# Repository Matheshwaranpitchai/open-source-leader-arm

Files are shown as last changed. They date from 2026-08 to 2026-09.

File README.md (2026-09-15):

# Open-source Leader Arm

Open-source, low-cost, 3D-printed leader arm for teleoperating an SO-ARM 

https://github.com/user-attachments/assets/977a0b56-c7d2-4a90-b86a-445dd3963871

A leader arm is moved by an operator to teleoperate a follower robot arm. A leader arm's joints are never driven, they simply report their joint angles, which the follower mirrors. So instead of using expensive servos, a cheap magnetic encoder like the AS5600 can be used. It results in an arm which is lighter to move by hand and is much cheaper than the one built with servos. 

Currently, the leader arm is tested against a simulated SO-ARM in MuJoCo with live physics, so you can pick up and move objects in the scene without a physical follower arm. It also plugs into LeRobot as a teleoperator, so you can record training datasets entirely in simulation.

## Featured Build

Oliver Choy independently built the Leader Arm and documented the process, including the ROS 2 implementation. He'll also be showcasing it at ROSCon 2026. [Read about his build →](https://www.linkedin.com/pulse/building-sub-50-3d-printed-robotic-arm-ros-2-little-oliver-choy-22amc/)

## Bill of materials

|Component| Quantity | Price|
|-|-|-|
|AS5600 encoder + Diametric magnet (5mm dia,2mm thick) | 6 | 6 x 186 INR = 1,116 INR (~11.7 USD)|
|608 Bearing (8x22x7mm) | 6 | 6 x 30 INR = 180 INR (~1.9 USD)|
| CJMCU TCA9548A I2C 8 Channel Multiplexer| 1 | 59 INR (~0.6 USD)|
|ESP32 | 1 | 550 INR (~5.8 USD)|
|28 AWG Silicon Wires | ~5m per color (4 colors) | 477 INR (~ 5 USD)|
|M3x10mm screws | 60 | 195 INR (~2 USD)|
|7x9cm Perfboard | 1 | 42 INR (~0.45 USD)|
| Rubber band | 1 | Negligible|
| |Total | 2,619 INR (~27.45 USD)|

Excluding the price of the 3D printed parts.

For context: the STS3215 servo used in the standard LeRobot leader arm costs around 24 USD each, and the leader arm needs six, roughly 144 USD in servos alone. Our entire component list comes in under 28 USD.

Note: The encoder and diametric magnet almost always come as a combo. Try to buy them together, the diametric magnet on its own can be difficult to source. 

## How it works?
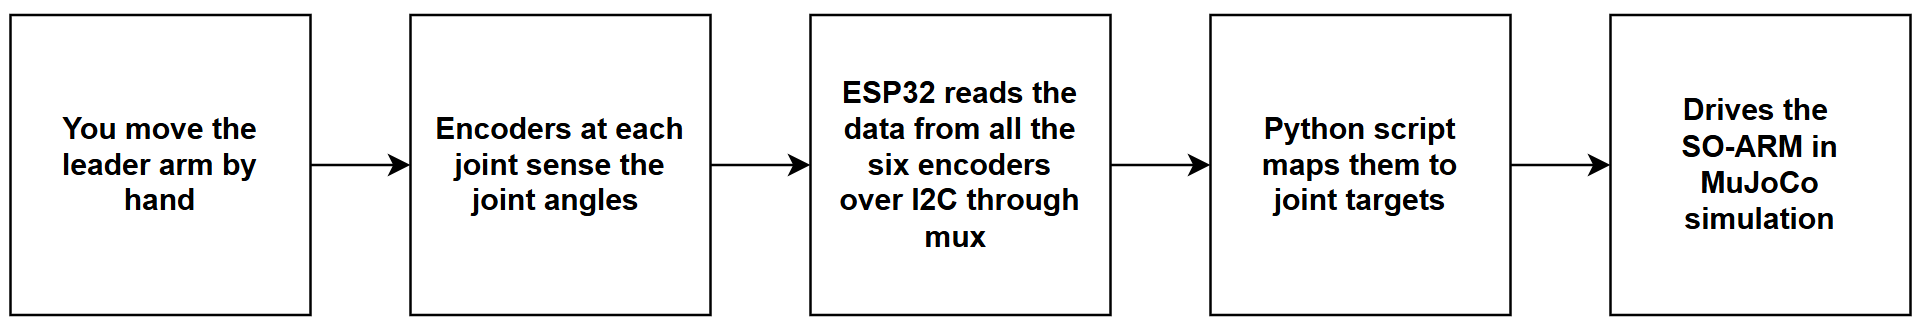
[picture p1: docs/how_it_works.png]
How it works explainer


**Why a mux?** - The AS5600 encoder has a fixed I2C address (0x36) and can't be changed. So we can't put more than one on a bus as they will all share the same address. The TCA9548A mux gives each encoder its own separate channel and connects one channel to the ESP32 at a time, so all six encoders can be read without any collision. 

## Wiring
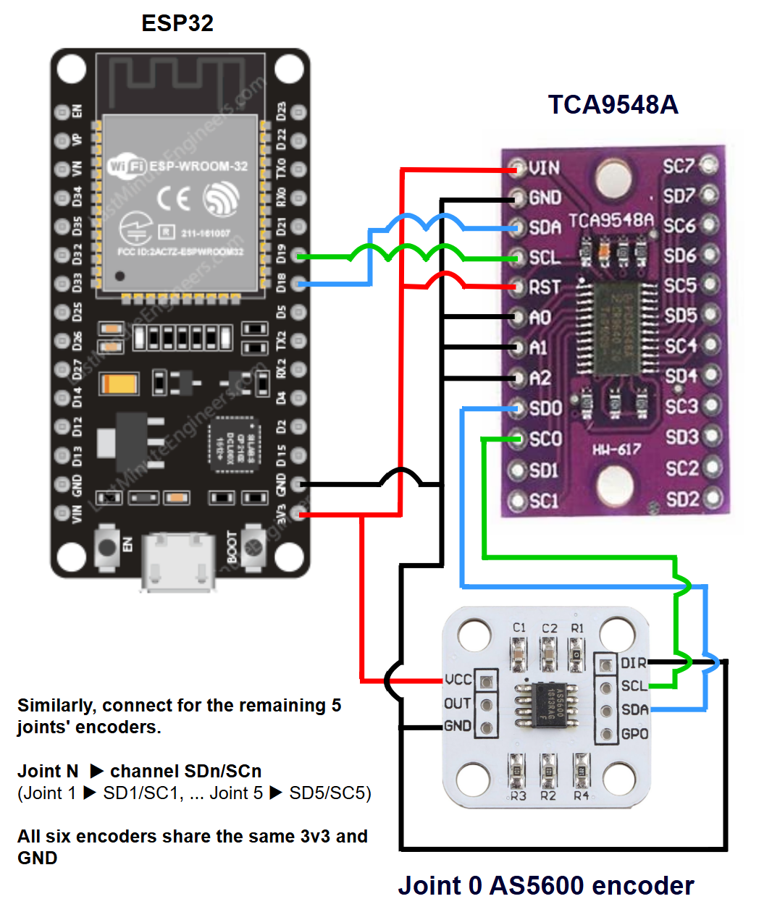
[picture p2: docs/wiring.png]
wiring diagram


| TCA9548A | ESP32 | 
| --- | --- |
| VIN | 3V3 |
| GND | GND |
| SDA | D18 |
| SCL | D19 |
| RST | 3V3 |
| A0, A1, A2 | GND |

| AS5600 | ESP32 |
| --- | --- |
| VCC | 3V3 |
| GND, DIR | GND |

| AS5600 | TCA9548A |
|---|---|
| SDA | SDn |
| SCL | SCn |

n = the channel for that joint \
joint 0 → SD0/SC0, ... joint 5 → SD5/SC5

## Print Settings

Printed in PLA, 0.2mm layer height and 15% infill.

There are 19 unique parts and a total of 49 parts. All the parts are designed to not need support while printing. All the parts are already oriented for printing; if any part loads at an odd angle, lay its flat face on the bed. 

The part 'bearing_housing' needs a bearing inserted mid-print. Add a pause at 10mm height (layer 50 at 0.2mm layer height setting). In Bambu studio, right-click the corresponding layer on the vertical slider and choose "Add Pause". When the printer pauses, insert the 608 bearing into the pocket, make sure it is seated flat, and then resume.

### Parts list and count

```
1 x base
1 x base_connector
6 x bearing_housing
6 x encoder_housing
5 x encoder_housing_cap
6 x rotor 
3 x link_perpendicular_base
3 x link_perpendicular_body
1 x link_shoulder_to_elbow
1 x link_elbow_to_wrist
1 x link_tooltip 
3 x washer_perpendicular_link 
3 x washer_round
1 x handle_base
1 x handle_body
1 x rest_pose_holder_base
1 x rest_pose_holder_body
3 x wire_holder
2 x rubberband_housing
```

## Firmware

Flash firmware.ino to the ESP32 using the Arduino IDE: 

1. Install the ESP32 board support (Tools → Board → Boards Manager → search "esp32")
2. Open 'firmware/firmware.ino' and select your ESP32 board and port, and upload.
3. After uploading, open the serial monitor at **115200 baud rate** to check the output.

The firmware uses only the built-in 'Wire' library, so there's nothing else to install.

On boot it prints a channel scan, one line per channel, naming whatever is wrong: "no device at 0x36" for a wiring or power fault, or "magnet too weak / too far", "too strong / too close" or "not detected" for a magnet fault.

If everything works then it prints "magnet ok"

Example : # ch0: AS5600 found, magnet ok, raw 1234

After the scan, it streams the six encoder readings as a comma-separated line, at 100 Hz. A channel that cannot be read sends "-1" in place of its angle.

## Running the software

Two ways to drive the follower arm: using LeRobot plugins (recommended), which work with a physical or a simulated follower, or the standalone scripts, which drive the simulated follower only. The follower arm in both methods starts in the SO-ARM rest pose, so hold the leader in its reference pose and press ENTER when prompted. That aligns both arms.

### Simulator setup

Skip this if you are using a physical follower. The simulator needs the SO-ARM model from MuJoCo Menagerie; the full repo is 2.35 GB, so pull only the SO-ARM100 folder (6.5 MB).
From the repo root:
```bash
git clone --depth 1 --filter=blob:none --sparse https://github.com/google-deepmind/mujoco_menagerie.git
cd mujoco_menagerie
git sparse-checkout set trs_so_arm100
cd ..
```
### Method 1 - using LeRobot plugins

Two plugins in this repo make the arm work inside [LeRobot](https://github.com/huggingface/lerobot):

- `lerobot_teleoperator_encoder_leader` - registers this leader arm as a LeRobot `Teleoperator`, so it replaces the servo leader in LeRobot's standard commands.
- `lerobot_robot_mujoco_so_arm` - registers a MuJoCo-simulated SO-ARM100 as a LeRobot `Robot`, so you can run the whole pipeline without a physical follower.

From the repo root (Python 3.10 or newer):
```bash
pip install lerobot
pip install -e lerobot_teleoperator_encoder_leader
pip install -e lerobot_robot_mujoco_so_arm
```

#### Teleoperate the arm

```bash
lerobot-teleoperate `
  --robot.type=so101_follower --robot.port=COM6 --robot.id=my_follower `
  --teleop.type=encoder_leader --teleop.port=COM3 --teleop.id=my_leader
```

Replace `COM3` with your ESP32's port. It's the same one the Arduino IDE showed when you flashed the firmware; on Linux and macOS it looks like `/dev/ttyUSB0`. Replace `COM6` with your follower's port.

When prompted, make sure the follower is in its rest pose, then hold the leader in its reference pose and press ENTER. That zeroes the encoders against the follower's rest pose.

Swap `--robot.type=mujoco_so_arm --robot.id=sim --robot.scene=mujoco_menagerie/trs_so_arm100/scene.xml` and drop `--robot.port` to drive the follower in simulation.

#### Record a dataset with a physical follower

```bash
lerobot-record `
  --robot.type=so101_follower --robot.port=COM6 --robot.id=my_follower `
  --robot.cameras="{top: {type: opencv, index_or_path: 0, width: 640, height: 480, fps: 30}, wrist: {type: opencv, index_or_path: 1, width: 640, height: 480, fps: 30}}" `
  --teleop.type=encoder_leader --teleop.port=COM3 --teleop.id=my_leader `
  --dataset.repo_id=<hf_user>/so_arm_sort --dataset.num_episodes=50 `
  --dataset.single_task="Put the red block in the left bin"
```
Replace `<hf_user>` with your huggingface username.
For more, see [Record a dataset](https://huggingface.co/docs/lerobot/main/en/lerobot-dataset-v3#record-a-dataset) in the LeRobot docs.

#### Record a dataset in simulation

```bash
lerobot-record `
  --robot.type=mujoco_so_arm --robot.id=sim `
  --robot.scene=mujoco_menagerie/trs_so_arm100/scene.xml --robot.viewer=true `
  --teleop.type=encoder_leader --teleop.port=COM3 --teleop.id=my_leader `
  --dataset.repo_id=<hf_user>/so_arm_sort --dataset.num_episodes=50 `
  --dataset.single_task="Put the red block in the left bin"
```
Replace `<hf_user>` with your huggingface username.
The scene comes with a block-sorting task: three coloured blocks and three matching bins.

Between episodes the blocks get rearranged into new positions. The plugin watches the same keys `lerobot-record` already uses (Right/Left, or `n`/`r`), so there is nothing extra to press and nothing to do during the reset window.

If you end episodes by timeout rather than by keypress, match both of `lerobot-record`'s timers or the episode tracking drifts:

```bash
  --dataset.episode_time_s=30 --robot.episode_time_s=30 `
  --dataset.reset_time_s=10  --robot.reset_time_s=10
```

Set the recording rate with `--dataset.fps` (default is 30). On integrated graphics 30 is about the limit; drop to 25 if the loop lags behind it.

Shadows and reflections are left out of the recorded images to keep the render cheap.

### Method 2 - using standalone scripts

No LeRobot needed; the encoder stream drives MuJoCo directly.

```bash
pip install "mujoco>=3.2" pyserial
```
Run either one.
```bash
python teleop.py --port COM3              # plain teleop, empty scene
python teleop_sort_task.py --port COM3    # teleop + block sorting
```

On Linux, the port looks like `/dev/ttyUSB0`.

In `teleop_sort_task.py`, press `R` in the viewer to reset the blocks.

## Assembly guide

This leader arm has six joints, `joint_0` to `joint_5`.
### Before you start : 
- See the print settings section for the full parts list and count
- Use the images in the guide for parts orientation and alignment. The assembly files under cad_files are also helpful for this.
- Notation : A + B means "attach part B to part A or assembly A". assembly_step_N refers to the result of step N. 
- Only joint_0 and joint_5 get their encoder attached immediately. The remaining four joints get their encoders at the very end, so that there is less wire clutter during the assembly.
 
### Steps : 
1. Start by wiring all the six encoders as shown in `wiring.png`.
2. insert the diametric magnet into the circular pocket provided in the `rotor` (for all 6 rotors)
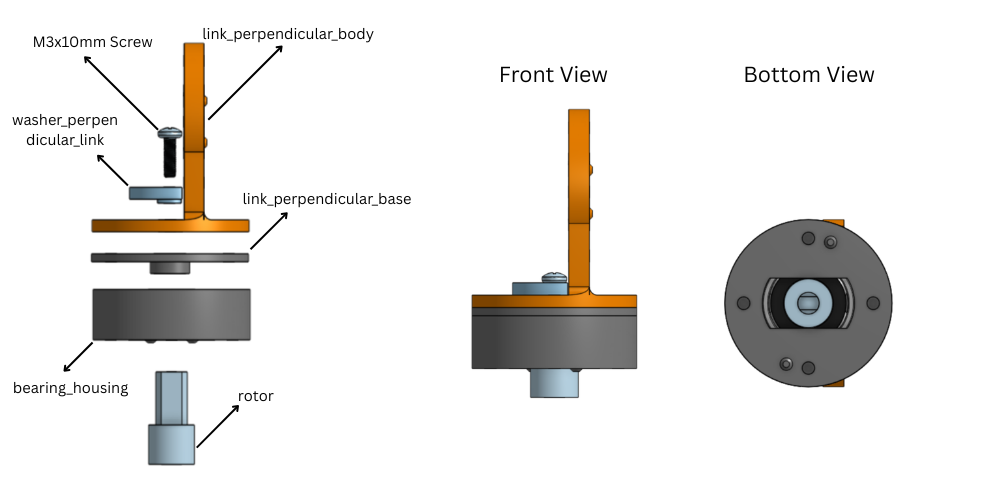
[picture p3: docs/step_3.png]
step_3
3. `rotor + bearing_housing + link_perpendicular_base + link_perpendicular_body + washer_perpendicular_link` (`joint_0`)
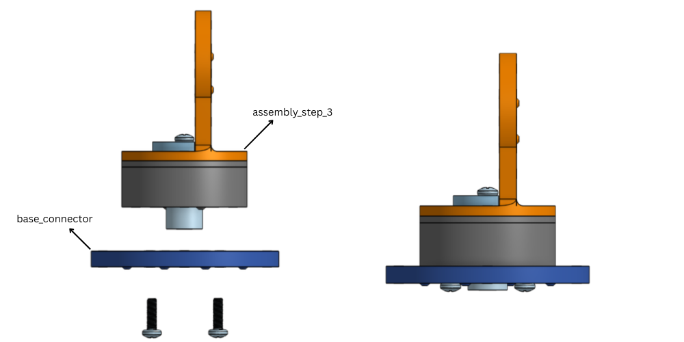
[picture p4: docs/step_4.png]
step_4
4. `assembly_step_3 + base_connector` 
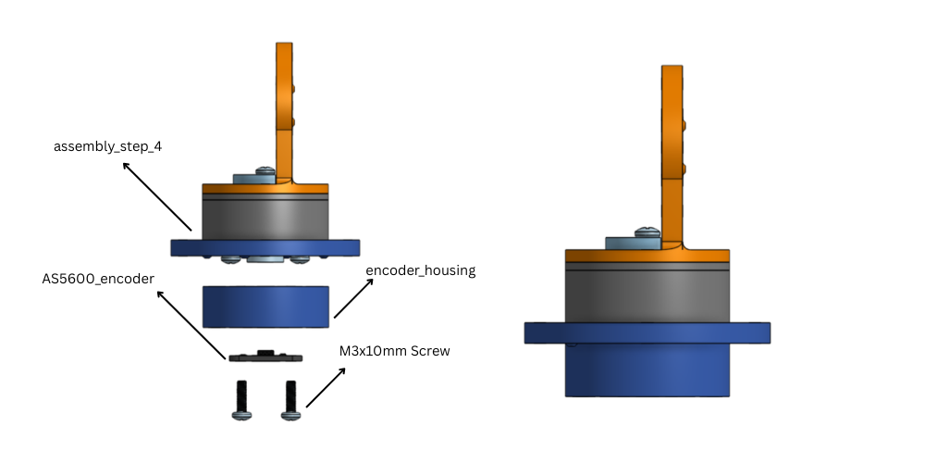
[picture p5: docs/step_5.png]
step_5
5. `assembly_step_4 + encoder_housing + AS5600_encoder` 
6. Tie a knot in the wire, then attach the `encoder_housing_cap`, so that a wire pull doesn't act on the encoder. 
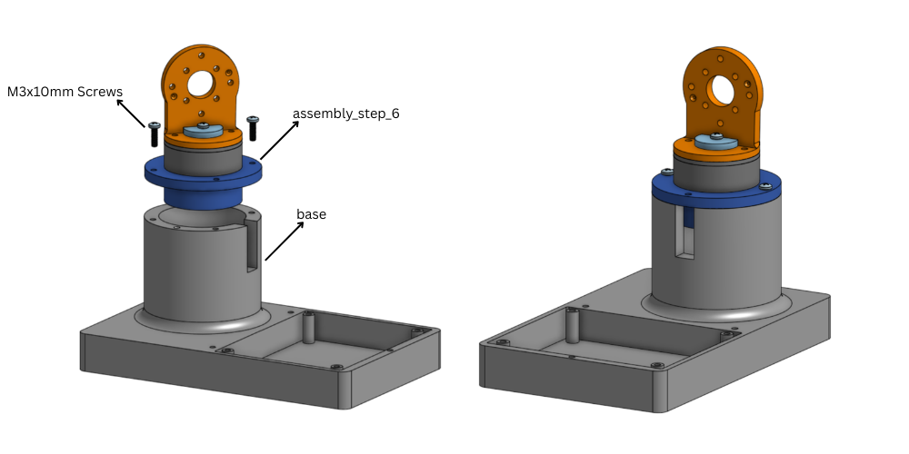
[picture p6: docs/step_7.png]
step_7
7. `assembly_step_6 + base` 
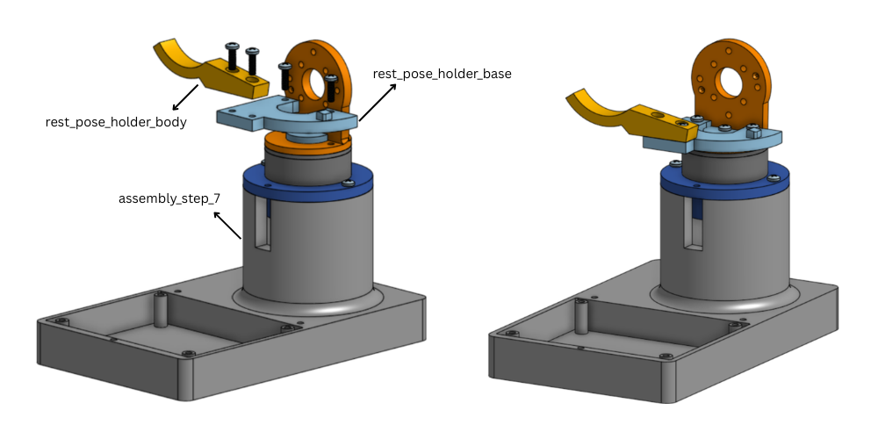
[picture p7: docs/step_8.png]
step_8
8. `assembly_step_7 + rest_pose_holder_base + rest_pose_holder_body` 
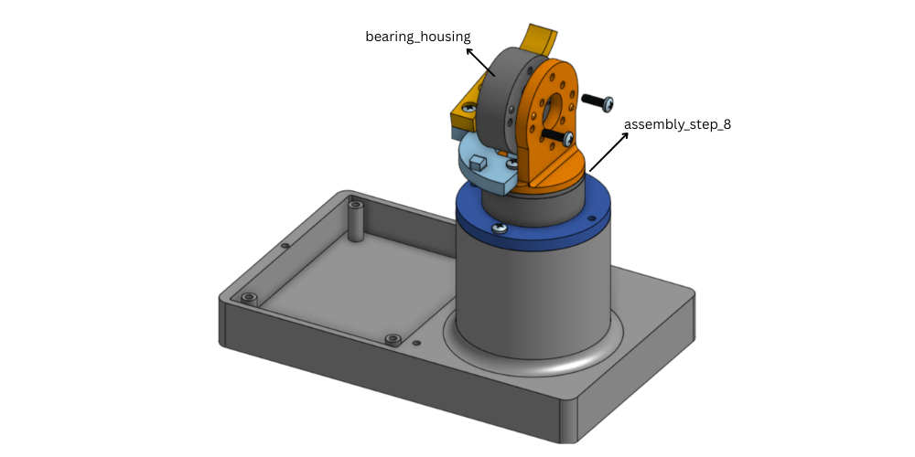
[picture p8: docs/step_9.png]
step_9
9. `assembly_step_8 + bearing_housing` 
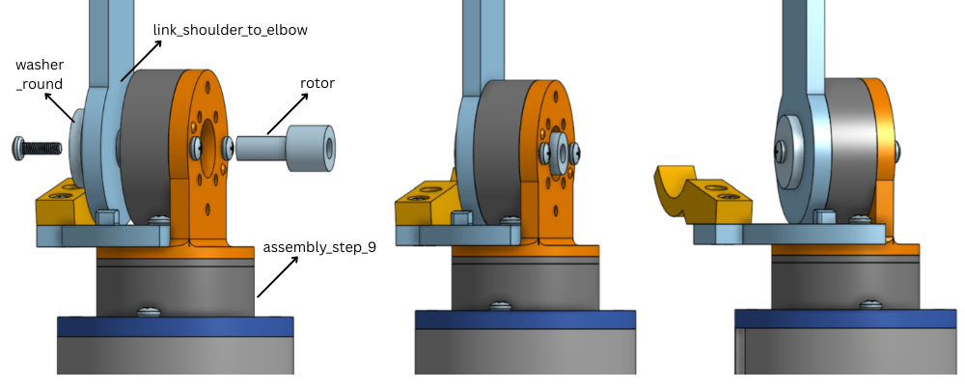
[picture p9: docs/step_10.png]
step_10
10. `assembly_step_9 + rotor + link_shoulder_to_elbow + washer_round` (`joint_1`) 
11. `link_shoulder_to_elbow + bearing_housing` (similar to step 9)
12. `assembly_step_11 + rotor + link_elbow_to_wrist + washer_round` (similar to step 10) (`joint_2`)
13. `link_elbow_to_wrist + bearing_housing` (similar to step 11)
14. `assembly_step_13 + rotor + link_perpendicular_base + link_perpendicular_body + washer_perpendicular_link` (similar to step 3) (`joint_3`)
15. `assembly_step_14 + bearing_housing` (similar to step 9)
16. `assembly_step_15 + rotor + link_perpendicular_base + link_perpendicular_body + washer_perpendicular_link` (similar to step 14) (`joint_4`)
17. `assembly_step_16 + bearing_housing` (similar to steps 9 and 15)
18. `assembly_step_17 + rotor + link_tooltip + washer_round` (`joint_5`)
19. `assembly_step_18 + encoder_housing + AS5600_encoder`
20. Tie a knot in the wire as in step 6
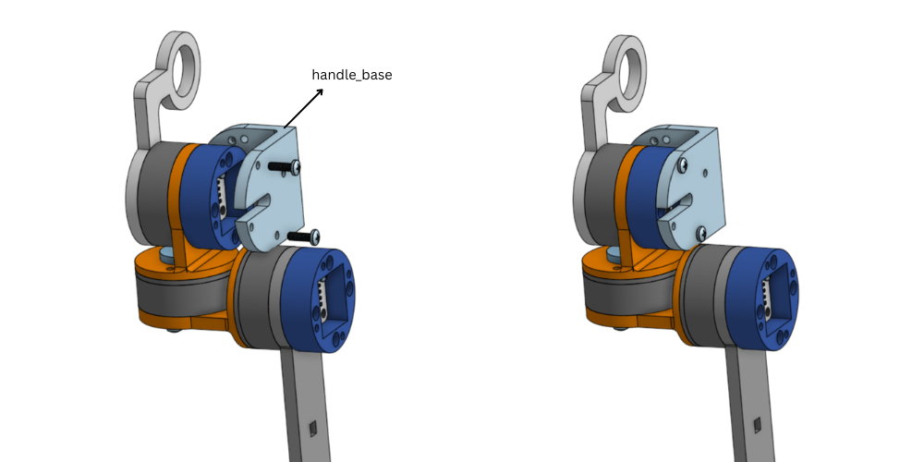
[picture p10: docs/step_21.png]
step_21
21. `assembly_step_20 + handle_base` (the `handle_base` also acts here as the `encoder_housing_cap`) 
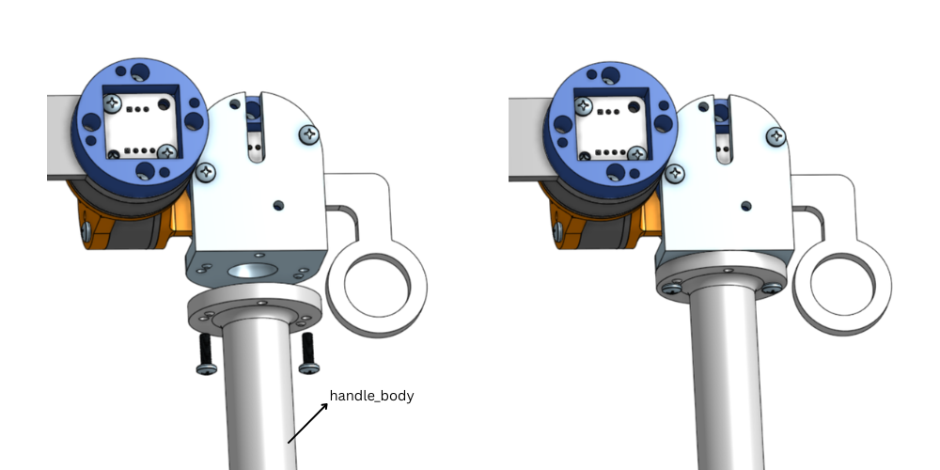
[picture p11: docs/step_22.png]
step_22
22. `assembly_step_21 + handle_body` 
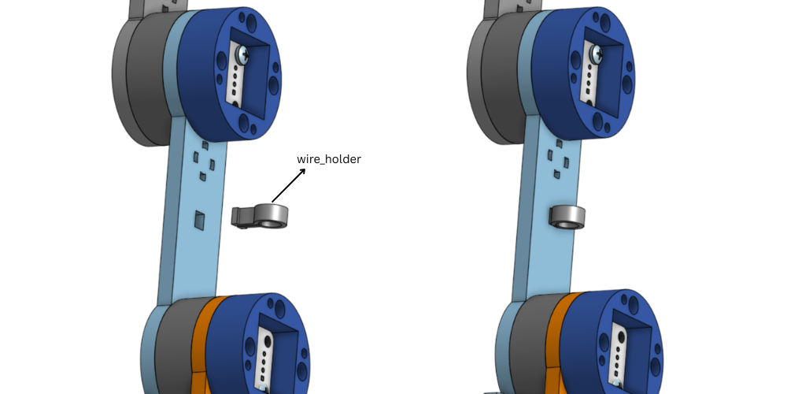
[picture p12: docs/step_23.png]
step_23
23. attach the three `wire_holder`s on `link_shoulder_to_elbow` and `link_elbow_to_wrist`. 
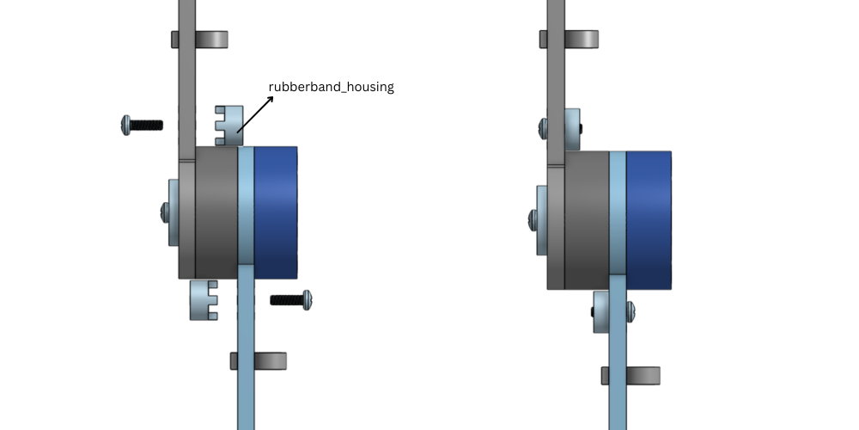
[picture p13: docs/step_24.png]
step_24
24. Route a single rubberband through both `rubberband_housings`, then fix one housing to `link_shoulder_to_elbow` and one to `link_elbow_to_wrist`. 
25. attach the `encoder_housing + AS5600_encoder`, tie a knot, and attach the `encoder_housing_cap` for the four remaining joints, in the same way as step 5 or step 19. 

## Acknowledgements

This project builds on the work of several open-source projects:

- [SO-ARM100](https://github.com/TheRobotStudio/SO-ARM100) - the follower arm design this leader is built to teleoperate.
- [LeRobot](https://github.com/huggingface/lerobot) - the leader/follower teleoperation approach this project is based on.
- [MuJoCo Menagerie](https://github.com/google-deepmind/mujoco_menagerie) - the SO-ARM model used by the simulated follower.

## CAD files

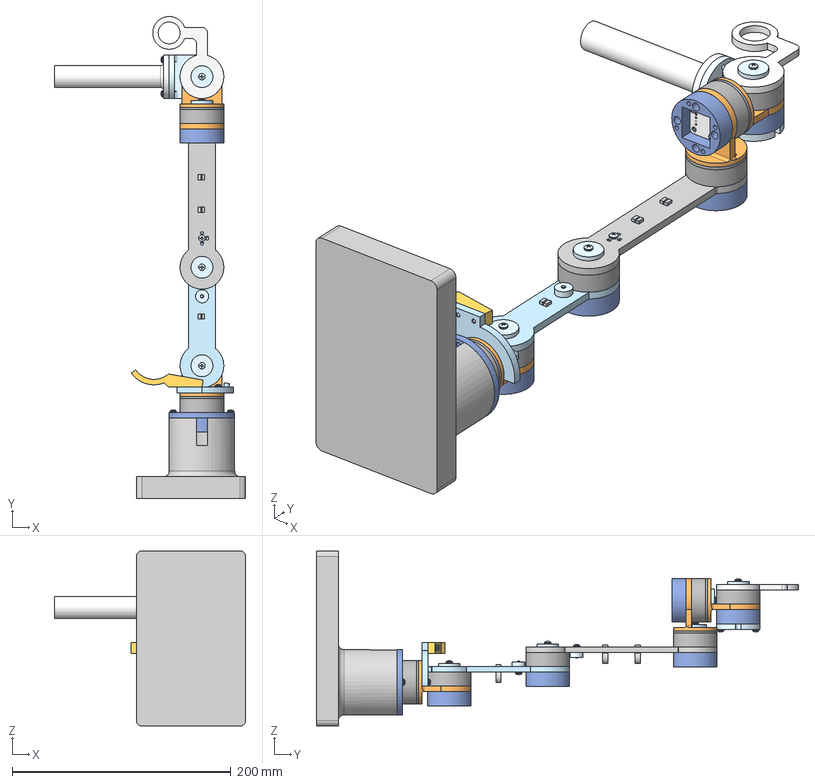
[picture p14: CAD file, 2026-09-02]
cad_files/assembly.step
175.0 x 440.7 x 160.0 mm
washer_round x 3
M3x10 PH Screw x 43
handle-body
bearing_housing x 6
washer_perpendicular_link x 3
rotor x 6
link_shoulder_to_elbow
608 bearing x 6
handle_base
rest_pose_holder_base
link_perpendicular_base x 3
wire_holder x 3
encoder_housing x 6
rest_pose_holder_body
link_perpendicular_body x 3
rubberband_housing x 2
base_connector
base
link_elbow_to_wrist
link_tooltip

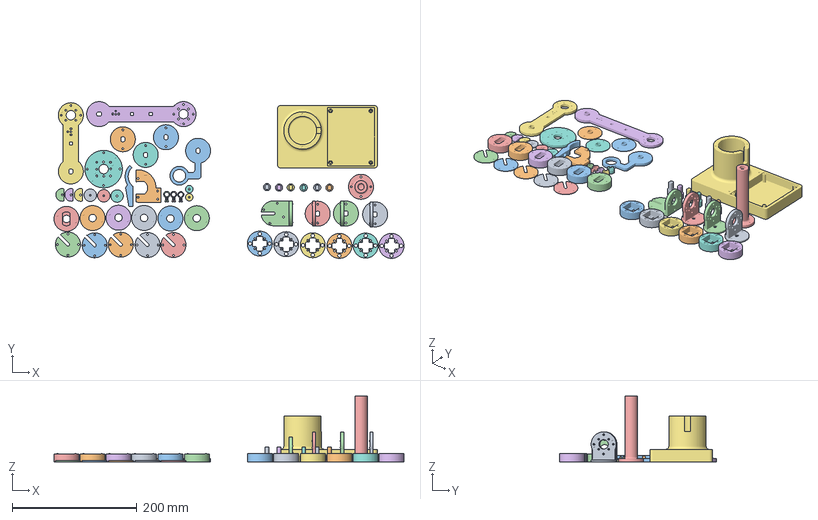
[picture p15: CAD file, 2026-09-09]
cad_files/leader_arm_all_parts_bambulab_a1.3mf
560.1 x 250.9 x 105.0 mm
bearing_housing.stl x 6
base.stl
base_connector.stl
encoder_cap.stl x 5
encoder_housing.stl x 6
handle_base.stl
handle_body.stl
link_elbow_to_wrist.stl
link_shoulder_to_elbow.stl
link_perpendicular_base.stl x 3
link_perpendicular_body.stl x 3
rotor.stl x 6
link_tooltip.stl
washer_perpendicular_link.stl x 3
washer_round.stl x 3
rest_pose_holder_base.stl
rest_pose_holder_body.stl
wire_holder.stl x 3
rubberband_housing.stl x 2

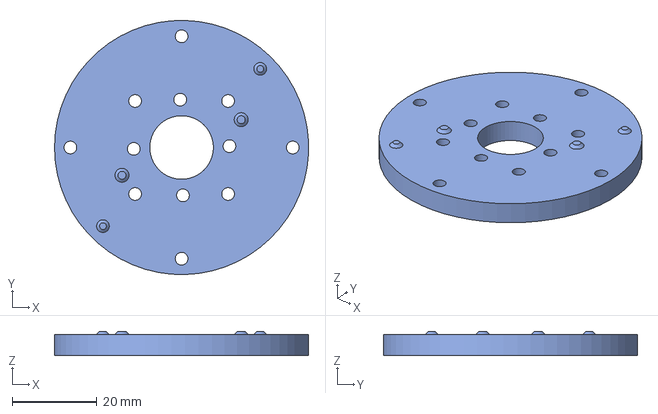
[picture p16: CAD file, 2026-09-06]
cad_files/step/base_connector.step
60.0 x 60.0 x 5.70 mm

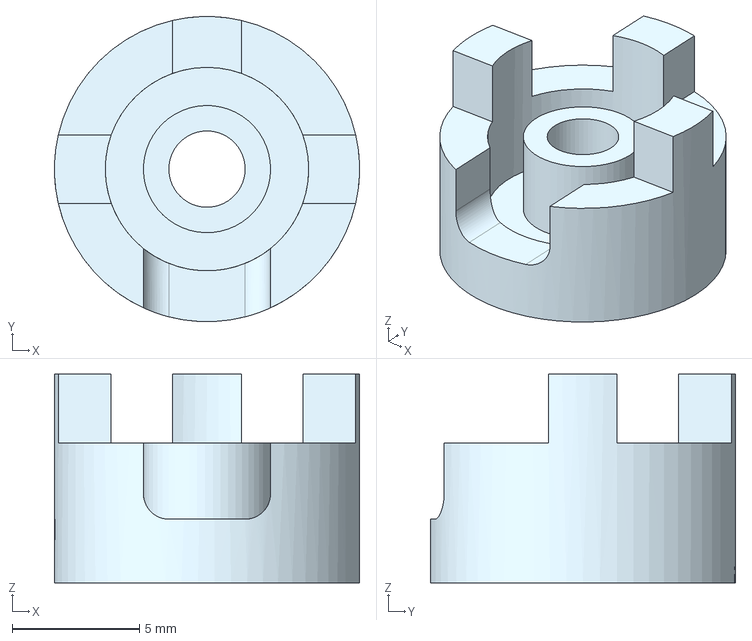
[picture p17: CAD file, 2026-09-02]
cad_files/step/rubberband_housing.step
12.0 x 12.0 x 8.20 mm

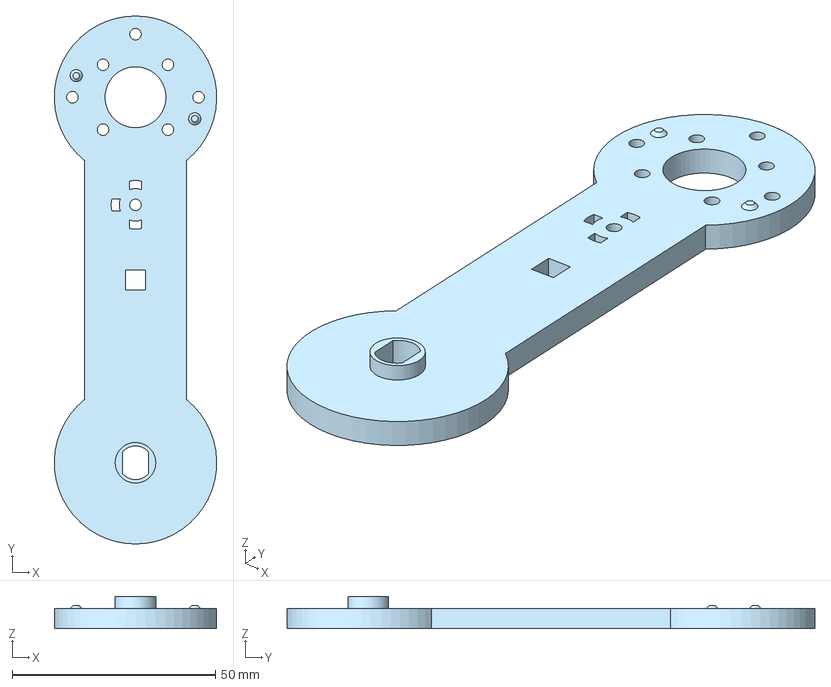
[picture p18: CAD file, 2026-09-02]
cad_files/step/link_shoulder_to_elbow.step
40.0 x 130.0 x 8.00 mm

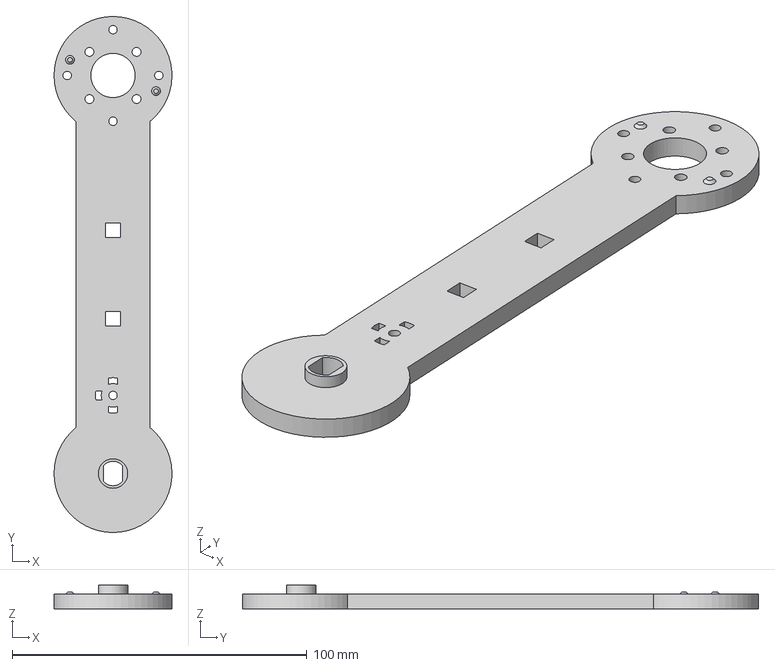
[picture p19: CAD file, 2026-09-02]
cad_files/step/link_elbow_to_wrist.step
40.0 x 175.0 x 8.00 mm

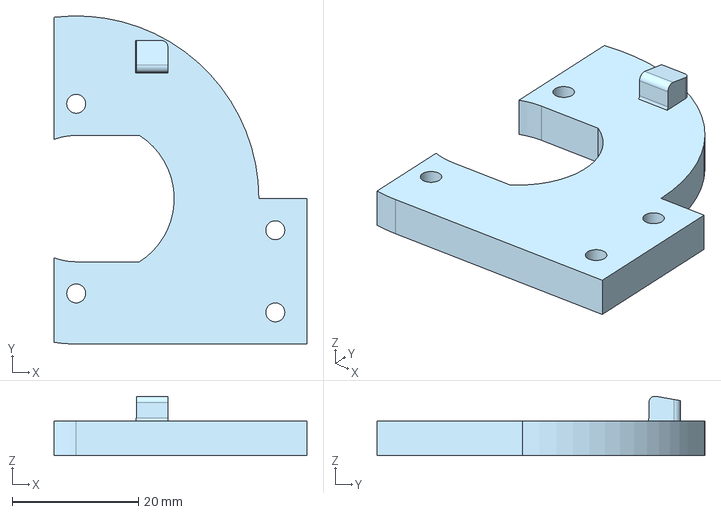
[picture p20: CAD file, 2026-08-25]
cad_files/step/rest_pose_holder_base.step
40.0 x 51.9 x 9.41 mm

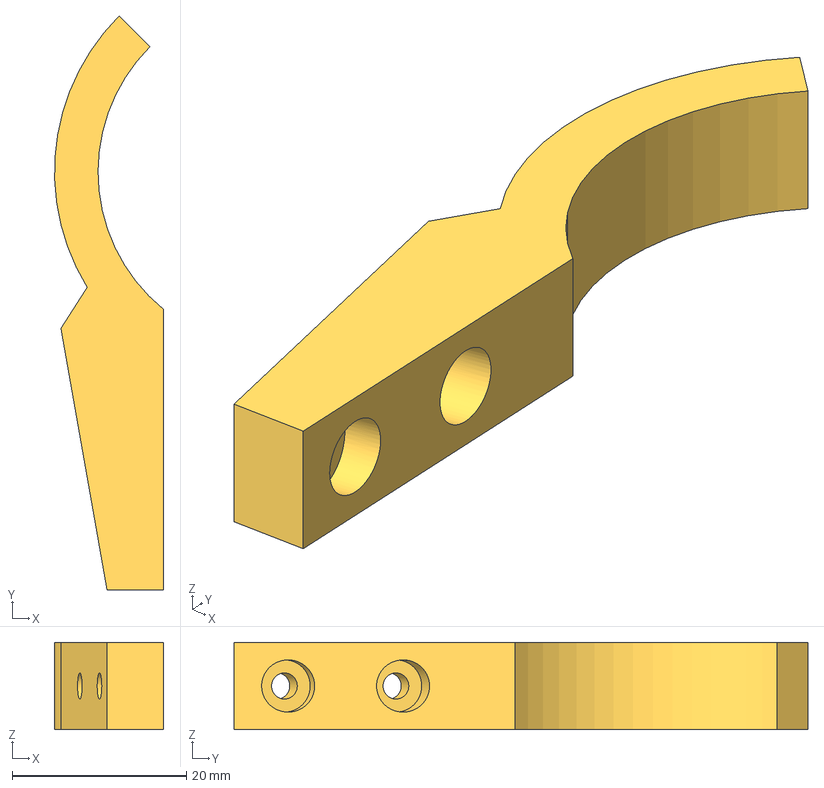
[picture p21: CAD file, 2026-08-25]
cad_files/step/rest_pose_holder_body.step
12.5 x 65.9 x 10.0 mm

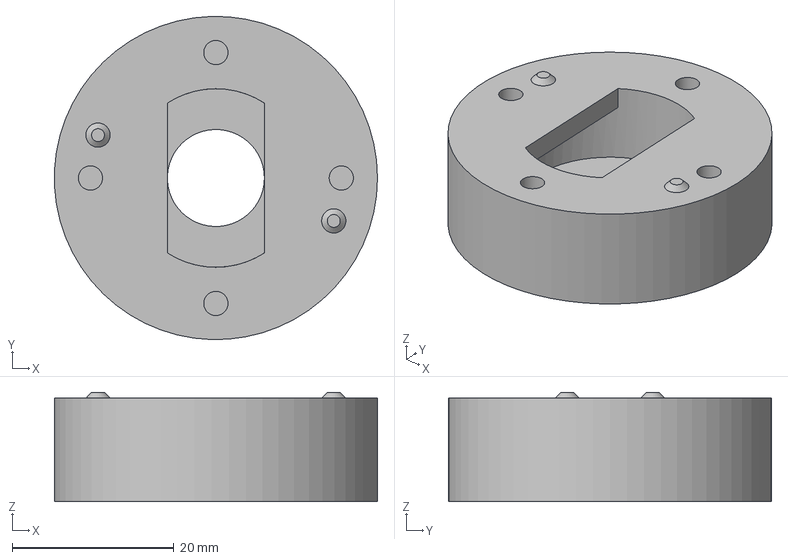
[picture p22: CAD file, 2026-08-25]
cad_files/step/bearing_housing.step
40.0 x 40.0 x 13.5 mm

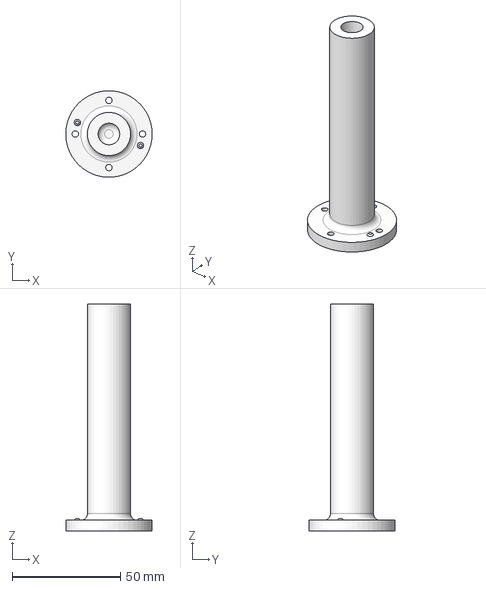
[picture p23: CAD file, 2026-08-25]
cad_files/step/handle_body.step
40.0 x 40.0 x 105.0 mm

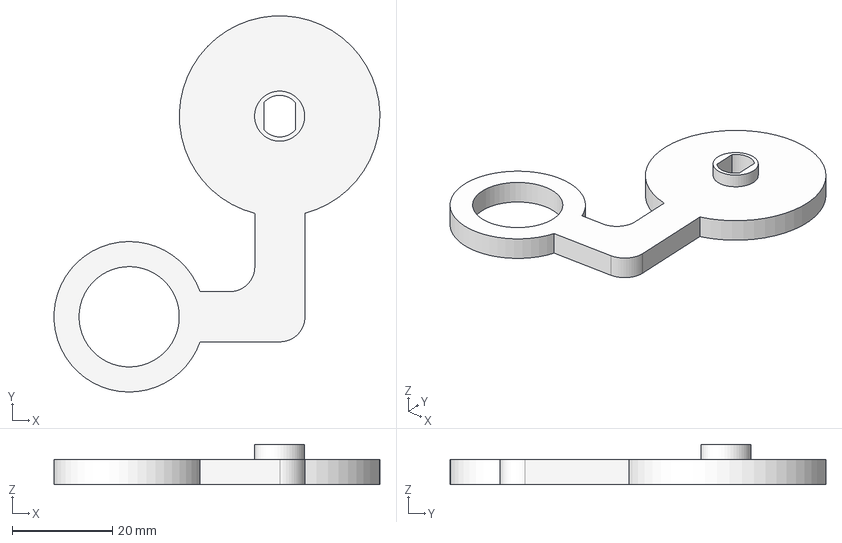
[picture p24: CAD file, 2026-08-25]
cad_files/step/link_tooltip.step
65.0 x 75.0 x 8.00 mm

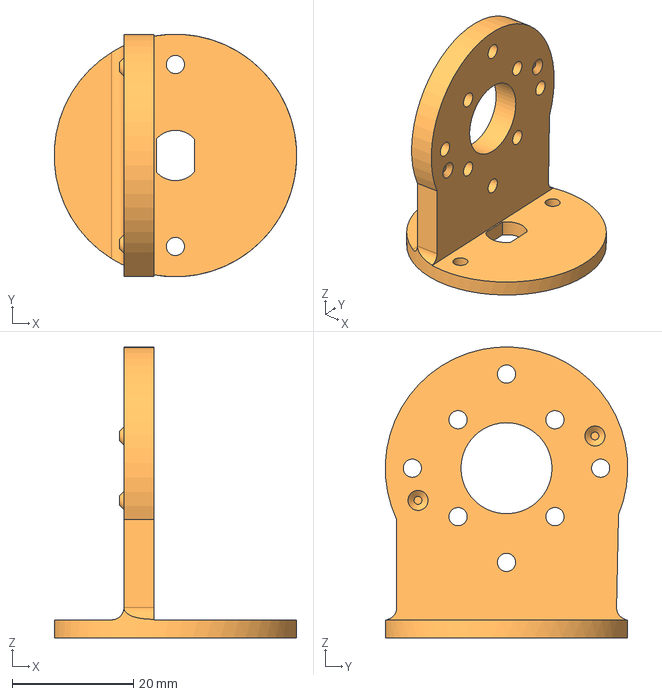
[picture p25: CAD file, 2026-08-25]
cad_files/step/link_perpendicular_body.step
40.0 x 40.0 x 48.0 mm

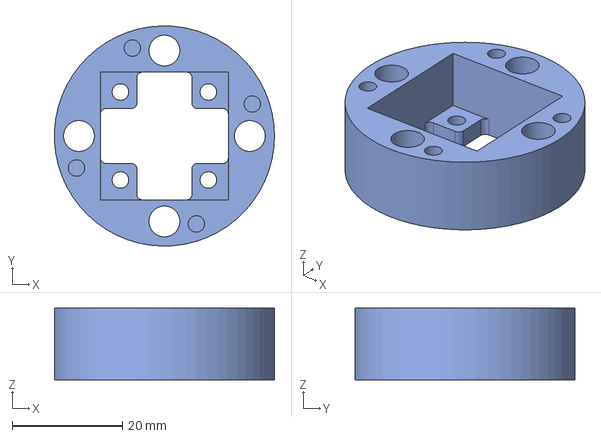
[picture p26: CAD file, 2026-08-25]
cad_files/step/encoder_housing.step
40.0 x 40.0 x 13.0 mm

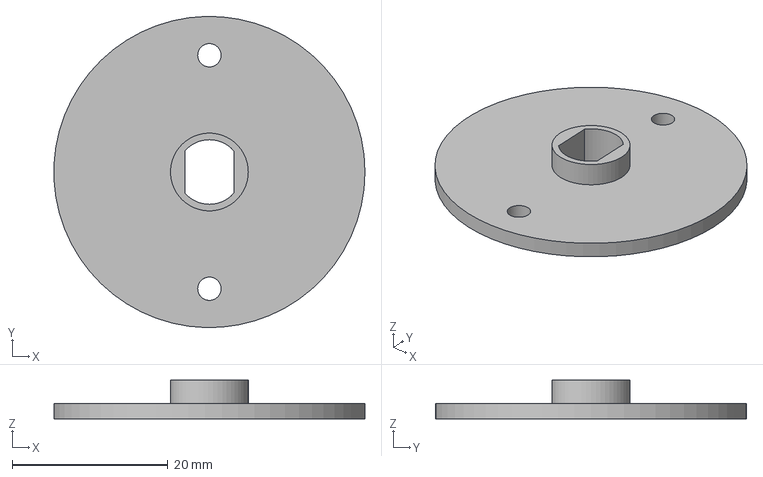
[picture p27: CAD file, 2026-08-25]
cad_files/step/link_perpendicular_base.step
40.0 x 40.0 x 5.00 mm

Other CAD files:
cad_files/step/link_elbow_to_shoulder.step
cad_files/step/wire_holder.step
cad_files/step/handle_base.step
cad_files/step/encoder_cap.step
cad_files/step/base.step
cad_files/step/rotor.step
cad_files/step/washer_perpendicular_link.step
cad_files/step/washer_round.step
cad_files/stl/base.stl
cad_files/stl/base_connector.stl
cad_files/stl/bearing_housing.stl
cad_files/stl/encoder_cap.stl
cad_files/stl/encoder_housing.stl
cad_files/stl/handle_base.stl
cad_files/stl/handle_body.stl
cad_files/stl/link_elbow_to_shoulder.stl
cad_files/stl/link_elbow_to_wrist.stl
cad_files/stl/link_perpendicular_base.stl
cad_files/stl/link_perpendicular_body.stl
cad_files/stl/link_shoulder_to_elbow.stl
cad_files/stl/link_tooltip.stl
cad_files/stl/rest_pose_holder_base.stl
cad_files/stl/rest_pose_holder_body.stl
cad_files/stl/rotor.stl
cad_files/stl/rubberband_housing.stl
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

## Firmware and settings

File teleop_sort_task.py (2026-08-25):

import argparse
import math
import time

import mujoco
import mujoco.viewer
import serial

SCENE = "mujoco_menagerie/trs_so_arm100/scene.xml"
COUNTS_PER_REV = 4096
RAD_PER_COUNT = 2 * math.pi / COUNTS_PER_REV

CHANNEL_TO_JOINT = {0: 0, 1: 1, 2: 2, 3: 3, 4: 4, 5: 5}
HOME_ANGLE = {0: -0.4517, 1: -3.32, 2: 3.1078, 3: 1.2338, 4: 0.1391, 5: -0.174}
DIRECTION = {0: -1, 1: -1, 2: -1, 3: -1, 4: 1, 5: 1}
SCALE = {0: 1.0, 1: 1.0, 2: 1.0, 3: 1.0, 4: 1.0, 5: 1.0}

BLOCK_SIZE = 0.015
BLOCK_MASS = 0.03
FRICTION = [1.2, 0.05, 0.001]
GRIP_GAIN = None

_Z = BLOCK_SIZE + 0.001
FORWARD_OFFSET = -0.10

COLORS = {
    "red":   [0.85, 0.20, 0.20, 1.0],
    "green": [0.20, 0.70, 0.25, 1.0],
    "blue":  [0.20, 0.45, 0.85, 1.0],
}

BLOCK_LAYOUT = [
    (-0.12, -0.20, "green"), (0.00, -0.20, "blue"), (0.12, -0.20, "red"),
]

BINS = [
    (-0.16, -0.36, "red"),
    (0.00, -0.36, "green"),
    (0.16, -0.36, "blue"),
]
BIN_HALF = [0.05, 0.05]
BIN_WALL = 0.004
BIN_WALL_H = 0.0125


def _blocks_spec():
    out = []
    for i, (x, y, color) in enumerate(BLOCK_LAYOUT):
        out.append({
            "name": f"block_{color}_{i}",
            "pos": [x, y + FORWARD_OFFSET, _Z],
            "color": color,
            "rgba": COLORS[color],
        })
    return out


BLOCKS = _blocks_spec()
BINS_ADJ = [(x, y + FORWARD_OFFSET, color) for (x, y, color) in BINS]


class Unwrapper:
    def __init__(self):
        self.last = None
        self.total = 0

    def update(self, raw):
        if raw < 0:
            return self.total
        if self.last is None:
            self.last = raw
        d = raw - self.last
        if d > COUNTS_PER_REV // 2:
            d -= COUNTS_PER_REV
        elif d < -COUNTS_PER_REV // 2:
            d += COUNTS_PER_REV
        self.last = raw
        self.total += d
        return self.total


def latest_line(ser, buf):
    buf += ser.read(ser.in_waiting or 1)
    if b"\n" not in buf:
        return None, buf
    *complete, buf = buf.split(b"\n")
    for line in reversed(complete):
        line = line.strip()
        if line and not line.startswith(b"#"):
            return line, buf
    return None, buf


def parse_counts(line):
    try:
        return [int(x) for x in line.split(b",")]
    except ValueError:
        return None


def read_good_counts(ser):
    buf = b""
    need = max(CHANNEL_TO_JOINT) + 1
    last_report = 0
    last_line = None
    while True:
        line, buf = latest_line(ser, buf)
        if line is not None:
            last_line = line
            counts = parse_counts(line)
            if counts and len(counts) >= need and all(
                counts[c] >= 0 for c in CHANNEL_TO_JOINT
            ):
                return counts
        now = time.time()
        if now - last_report > 1.0:
            last_report = now
            if last_line is None:
                print("  waiting... no serial data yet (right port? streaming?)")
            else:
                counts = parse_counts(last_line)
                if not counts:
                    print(f"  waiting... unreadable line: {last_line!r}")
                elif len(counts) < need:
                    print(f"  waiting... only {len(counts)} values, need {need}"
                          f" -- re-flash firmware with N_CH={need}")
                else:
                    bad = [c for c in CHANNEL_TO_JOINT if counts[c] < 0]
                    print(f"  waiting... channel(s) {bad} reading -1"
                          f" -- fix that encoder's magnet/wiring")


def _add_bin(spec, cx, cy, color):
    name = f"bin_{color}"
    bhx, bhy = BIN_HALF
    wt, wh = BIN_WALL, BIN_WALL_H
    pad_rgba = COLORS[color]
    wall_rgba = [pad_rgba[0], pad_rgba[1], pad_rgba[2], 0.40]

    body = spec.worldbody.add_body(name=name, pos=[cx, cy, 0.0])

    pad = body.add_geom()
    pad.name = f"{name}_pad"
    pad.type = mujoco.mjtGeom.mjGEOM_BOX
    pad.size = [bhx + 2 * wt, bhy + 2 * wt, 0.001]
    pad.pos = [0.0, 0.0, 0.001]
    pad.rgba = pad_rgba

    walls = [
        (f"{name}_e", [bhx + wt, 0.0, wh], [wt, bhy + 2 * wt, wh]),
        (f"{name}_w", [-(bhx + wt), 0.0, wh], [wt, bhy + 2 * wt, wh]),
        (f"{name}_n", [0.0, bhy + wt, wh], [bhx + 2 * wt, wt, wh]),
        (f"{name}_s", [0.0, -(bhy + wt), wh], [bhx + 2 * wt, wt, wh]),
    ]
    for gname, gpos, gsize in walls:
        w = body.add_geom()
        w.name = gname
        w.type = mujoco.mjtGeom.mjGEOM_BOX
        w.pos = gpos
        w.size = gsize
        w.rgba = wall_rgba


def build_model():
    spec = mujoco.MjSpec.from_file(SCENE)
    for b in BLOCKS:
        body = spec.worldbody.add_body(name=b["name"], pos=b["pos"])
        body.add_freejoint()
        geom = body.add_geom()
        geom.type = mujoco.mjtGeom.mjGEOM_BOX
        geom.size = [BLOCK_SIZE, BLOCK_SIZE, BLOCK_SIZE]
        geom.rgba = b["rgba"]
        geom.friction = FRICTION
        geom.mass = BLOCK_MASS
    for cx, cy, color in BINS_ADJ:
        _add_bin(spec, cx, cy, color)
    return spec.compile()


def block_registry(model):
    reg = []
    for b in BLOCKS:
        bid = mujoco.mj_name2id(model, mujoco.mjtObj.mjOBJ_BODY, b["name"])
        jid = model.body_jntadr[bid]
        reg.append({
            "name": b["name"],
            "color": b["color"],
            "bid": bid,
            "qadr": model.jnt_qposadr[jid],
            "vadr": model.jnt_dofadr[jid],
            "start": list(b["pos"]),
        })
    return reg


def reset_blocks(model, data, blocks_reg):
    for blk in blocks_reg:
        q = blk["qadr"]
        data.qpos[q:q + 3] = blk["start"]
        data.qpos[q + 3:q + 7] = [1.0, 0.0, 0.0, 0.0]
        v = blk["vadr"]
        data.qvel[v:v + 6] = 0.0
    mujoco.mj_forward(model, data)


def main():
    p = argparse.ArgumentParser()
    p.add_argument("--port", required=True)
    p.add_argument("--baud", type=int, default=115200)
    p.add_argument("--list", action="store_true")
    args = p.parse_args()

    model = build_model()
    data = mujoco.MjData(model)
    blocks_reg = block_registry(model)

    joint_to_act = {}
    for a in range(model.nu):
        if model.actuator_trntype[a] == mujoco.mjtTrn.mjTRN_JOINT:
            joint_to_act[int(model.actuator_trnid[a, 0])] = a

    if args.list:
        for j in range(model.njnt):
            name = mujoco.mj_id2name(model, mujoco.mjtObj.mjOBJ_JOINT, j)
            act = joint_to_act.get(j)
            aname = (mujoco.mj_id2name(model, mujoco.mjtObj.mjOBJ_ACTUATOR, act)
                     if act is not None else "-- no actuator")
            print(f"joint {j}: {name}  -> actuator {act} ({aname})")
        return

    if GRIP_GAIN is not None:
        gjoint = CHANNEL_TO_JOINT[5]
        gact = joint_to_act.get(gjoint)
        if gact is not None:
            model.actuator_gainprm[gact, 0] = GRIP_GAIN

    joints = {}
    for jidx in CHANNEL_TO_JOINT.values():
        act = joint_to_act.get(jidx)
        joints[jidx] = {
            "adr": model.jnt_qposadr[jidx],
            "act": act,
            "lo": model.jnt_range[jidx][0],
            "hi": model.jnt_range[jidx][1],
            "limited": bool(model.jnt_limited[jidx]),
        }
        if act is None:
            print(f"WARNING: joint {jidx} has no actuator; it won't be driven.")

    ser = serial.Serial(args.port, args.baud, timeout=0.05)
    unwrap = {ch: Unwrapper() for ch in CHANNEL_TO_JOINT}
    need = max(CHANNEL_TO_JOINT) + 1

    print("Hold the leader arm in its reference pose, then press ENTER...")
    input()
    home = read_good_counts(ser)
    zero_count = {ch: unwrap[ch].update(home[ch]) for ch in CHANNEL_TO_JOINT}

    for jidx in CHANNEL_TO_JOINT.values():
        data.qpos[joints[jidx]["adr"]] = HOME_ANGLE[jidx]
        if joints[jidx]["act"] is not None:
            data.ctrl[joints[jidx]["act"]] = HOME_ANGLE[jidx]
    mujoco.mj_forward(model, data)
    print("Homed. Sort the blocks into the matching-color bins. "
          "Press R in the viewer to reset the blocks.")

    def clamp(v, jinfo):
        return max(jinfo["lo"], min(jinfo["hi"], v)) if jinfo["limited"] else v

    reset_requested = [False]

    def key_callback(keycode):
        if keycode in (ord("R"), ord("r")):
            reset_requested[0] = True

    buf = b""
    wall0 = time.perf_counter()

    with mujoco.viewer.launch_passive(
        model, data, key_callback=key_callback
    ) as viewer:
        while viewer.is_running():
            if reset_requested[0]:
                reset_requested[0] = False
                reset_blocks(model, data, blocks_reg)

            line, buf = latest_line(ser, buf)
            if line is not None:
                counts = parse_counts(line)
                if counts and len(counts) >= need:
                    for ch, jidx in CHANNEL_TO_JOINT.items():
                        u = unwrap[ch].update(counts[ch])
                        delta = (u - zero_count[ch]) * RAD_PER_COUNT
                        delta *= DIRECTION[jidx] * SCALE[jidx]
                        target = clamp(HOME_ANGLE[jidx] + delta, joints[jidx])
                        act = joints[jidx]["act"]
                        if act is not None:
                            data.ctrl[act] = target

            target_time = time.perf_counter() - wall0
            steps = 0
            while data.time < target_time and steps < 50:
                mujoco.mj_step(model, data)
                steps += 1

            viewer.sync()


if __name__ == "__main__":
    main()

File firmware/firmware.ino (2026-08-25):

#include <Wire.h>

#define MUX_ADDR     0x70
#define AS5600_ADDR  0x36
#define N_CH         6
#define SDA_PIN      18
#define SCL_PIN      19
#define SAMPLE_HZ    100

#define REG_STATUS    0x0B
#define REG_RAW_ANGLE 0x0C

bool muxSelect(uint8_t ch) {
  if (ch >= 8) return false;
  Wire.beginTransmission(MUX_ADDR);
  Wire.write(1 << ch);
  return Wire.endTransmission() == 0;
}

void muxDisableAll() {
  Wire.beginTransmission(MUX_ADDR);
  Wire.write(0x00);
  Wire.endTransmission();
}

int16_t readRawAngle() {
  Wire.beginTransmission(AS5600_ADDR);
  Wire.write(REG_RAW_ANGLE);
  if (Wire.endTransmission(false) != 0) return -1;
  if (Wire.requestFrom(AS5600_ADDR, 2) != 2) return -1;
  uint8_t hi = Wire.read(), lo = Wire.read();
  return ((hi << 8) | lo) & 0x0FFF;
}

uint8_t readStatus() {
  Wire.beginTransmission(AS5600_ADDR);
  Wire.write(REG_STATUS);
  if (Wire.endTransmission(false) != 0) return 0;
  if (Wire.requestFrom(AS5600_ADDR, 1) != 1) return 0;
  return Wire.read();
}

void diagnose() {
  Serial.println("# channel scan");
  for (uint8_t ch = 0; ch < N_CH; ch++) {
    if (!muxSelect(ch)) {
      Serial.printf("# ch%u: mux not responding at 0x%02X\n", ch, MUX_ADDR);
      continue;
    }
    Wire.beginTransmission(AS5600_ADDR);
    if (Wire.endTransmission() != 0) {
      Serial.printf("# ch%u: no device at 0x36 -- check SDn/SCn and power\n", ch);
      continue;
    }
    uint8_t st = readStatus();
    const char *magnet = (st & 0x20) ? "ok"
                       : (st & 0x10) ? "too weak / too far"
                       : (st & 0x08) ? "too strong / too close"
                                     : "not detected";
    Serial.printf("# ch%u: AS5600 found, magnet %s, raw %d\n",
                  ch, magnet, readRawAngle());
  }
  muxDisableAll();
  Serial.println("# scan done");
}

void setup() {
  Serial.begin(115200);
  Wire.begin(SDA_PIN, SCL_PIN);
  Wire.setClock(400000);
  delay(300);
  diagnose();
}

void loop() {
  static uint32_t next = 0;
  const uint32_t period = 1000 / SAMPLE_HZ;
  if (millis() < next) return;
  next = millis() + period;

  int16_t angle[N_CH];
  for (uint8_t ch = 0; ch < N_CH; ch++) {
    angle[ch] = muxSelect(ch) ? readRawAngle() : -1;
  }

  for (uint8_t ch = 0; ch < N_CH; ch++) {
    Serial.print(angle[ch]);
    Serial.print(ch == N_CH - 1 ? '\n' : ',');
  }
}

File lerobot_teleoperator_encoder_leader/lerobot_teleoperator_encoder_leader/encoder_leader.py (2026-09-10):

import logging
import math
import time

import serial

from lerobot.teleoperators.teleoperator import Teleoperator
from lerobot.utils.decorators import check_if_already_connected, check_if_not_connected

from .config_encoder_leader import JOINTS, EncoderLeaderConfig

logger = logging.getLogger(__name__)


class _Unwrapper:
    def __init__(self, counts_per_rev: int):
        self.counts_per_rev = counts_per_rev
        self.last: int | None = None
        self.total = 0

    def update(self, raw: int) -> int:
        if raw < 0:
            return self.total
        if self.last is None:
            self.last = raw
        d = raw - self.last
        if d > self.counts_per_rev // 2:
            d -= self.counts_per_rev
        elif d < -self.counts_per_rev // 2:
            d += self.counts_per_rev
        self.last = raw
        self.total += d
        return self.total


class EncoderLeader(Teleoperator):
    config_class = EncoderLeaderConfig
    name = "encoder_leader"

    def __init__(self, config: EncoderLeaderConfig):
        super().__init__(config)
        self.config = config
        self.rad_per_count = 2 * math.pi / config.counts_per_rev
        self._ser: serial.Serial | None = None
        self._buf = b""
        self._unwrap = {ch: _Unwrapper(config.counts_per_rev) for ch in config.channel_to_joint}
        self._zero_count: dict[int, int] = {}


    @property
    def action_features(self) -> dict[str, type]:
        return {f"{j}.pos": float for j in JOINTS}

    @property
    def feedback_features(self) -> dict[str, type]:
        return {}


    @property
    def is_connected(self) -> bool:
        return self._ser is not None and self._ser.is_open

    @check_if_already_connected
    def connect(self, calibrate: bool = True) -> None:
        self._ser = serial.Serial(self.config.port, self.config.baudrate, timeout=self.config.timeout)
        time.sleep(1.5)
        self._ser.reset_input_buffer()
        self._buf = b""

        if calibrate:
            self.calibrate()

        logger.info(f"{self} connected on {self.config.port}")

    @check_if_not_connected
    def disconnect(self) -> None:
        self._ser.close()
        self._ser = None
        logger.info(f"{self} disconnected.")

    def configure(self) -> None:
        pass


    @property
    def is_calibrated(self) -> bool:
        return bool(self._zero_count)

    @check_if_not_connected
    def calibrate(self) -> None:
        input(f"Hold {self} in its reference pose, then press ENTER...")
        home = self._read_good_counts()
        self._zero_count = {
            ch: self._unwrap[ch].update(home[ch]) for ch in self.config.channel_to_joint
        }
        counts = [home[c] for c in sorted(self.config.channel_to_joint)]
        print(f"Homed on {counts}. Move the arm.")


    @check_if_not_connected
    def get_action(self) -> dict[str, float]:
        start = time.perf_counter()

        line = self._latest_line()
        if line is not None:
            counts = self._parse_counts(line)
            need = max(self.config.channel_to_joint) + 1
            if counts and len(counts) >= need:
                for ch in self.config.channel_to_joint:
                    self._unwrap[ch].update(counts[ch])

        action: dict[str, float] = {}
        for ch, jidx in self.config.channel_to_joint.items():
            delta = (self._unwrap[ch].total - self._zero_count[ch]) * self.rad_per_count
            delta *= self.config.direction[jidx] * self.config.scale[jidx]
            angle = self.config.home_angle[jidx] + delta

            lo, hi = self.config.joint_range[jidx]
            unit = (angle - lo) / max(hi - lo, 1e-9)
            unit = min(max(unit, 0.0), 1.0)

            name = JOINTS[jidx]
            if name == "gripper":
                action[f"{name}.pos"] = unit * 100.0
            else:
                action[f"{name}.pos"] = unit * 200.0 - 100.0

        dt_ms = (time.perf_counter() - start) * 1e3
        logger.debug(f"{self} read action: {dt_ms:.1f}ms")
        return action

    def send_feedback(self, feedback: dict[str, float]) -> None:
        pass

    def _latest_line(self) -> bytes | None:
        self._buf += self._ser.read(self._ser.in_waiting or 1)
        if b"\n" not in self._buf:
            return None
        *complete, self._buf = self._buf.split(b"\n")
        for line in reversed(complete):
            line = line.strip()
            if line and not line.startswith(b"#"):
                return line
        return None

    @staticmethod
    def _parse_counts(line: bytes) -> list[int] | None:
        try:
            return [int(x) for x in line.split(b",")]
        except ValueError:
            return None

    def _read_good_counts(self) -> list[int]:
        need = max(self.config.channel_to_joint) + 1
        last_report = 0.0
        last_line = None
        while True:
            line = self._latest_line()
            if line is not None:
                last_line = line
                counts = self._parse_counts(line)
                if (
                    counts
                    and len(counts) >= need
                    and all(counts[c] >= 0 for c in self.config.channel_to_joint)
                ):
                    return counts
            now = time.time()
            if now - last_report > 1.0:
                last_report = now
                if last_line is None:
                    print("  waiting... no serial data yet (right port? streaming?)")
                else:
                    counts = self._parse_counts(last_line)
                    if not counts:
                        print(f"  waiting... unreadable line: {last_line!r}")
                    elif len(counts) < need:
                        print(
                            f"  waiting... only {len(counts)} values, need {need}"
                            f" -- re-flash firmware with N_CH={need}"
                        )
                    else:
                        bad = [c for c in self.config.channel_to_joint if counts[c] < 0]
                        print(
                            f"  waiting... channel(s) {bad} reading -1"
                            f" -- fix that encoder's magnet/wiring"
                        )

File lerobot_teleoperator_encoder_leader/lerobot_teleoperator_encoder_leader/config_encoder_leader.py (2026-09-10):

from dataclasses import dataclass, field

from lerobot.teleoperators.config import TeleoperatorConfig

JOINTS = ["shoulder_pan", "shoulder_lift", "elbow_flex", "wrist_flex", "wrist_roll", "gripper"]


def _default_channel_to_joint() -> dict[int, int]:
    return {0: 0, 1: 1, 2: 2, 3: 3, 4: 4, 5: 5}


def _default_home_angle() -> dict[int, float]:
    return {0: -0.4517, 1: -3.32, 2: 3.1078, 3: 1.2338, 4: 0.1391, 5: -0.174}


def _default_direction() -> dict[int, int]:
    return {0: -1, 1: -1, 2: -1, 3: -1, 4: 1, 5: 1}


def _default_scale() -> dict[int, float]:
    return {0: 1.0, 1: 1.0, 2: 1.0, 3: 1.0, 4: 1.0, 5: 1.0}


def _default_joint_range() -> dict[int, tuple[float, float]]:
    return {
        0: (-1.92, 1.92),
        1: (-3.32, 0.174),
        2: (-0.174, 3.14),
        3: (-1.66, 1.66),
        4: (-2.79, 2.79),
        5: (-0.174, 1.75),
    }


@TeleoperatorConfig.register_subclass("encoder_leader")
@dataclass
class EncoderLeaderConfig(TeleoperatorConfig):
    port: str = "COM5"
    baudrate: int = 115200
    timeout: float = 0.05

    channel_to_joint: dict[int, int] = field(default_factory=_default_channel_to_joint)
    home_angle: dict[int, float] = field(default_factory=_default_home_angle)
    direction: dict[int, int] = field(default_factory=_default_direction)
    scale: dict[int, float] = field(default_factory=_default_scale)
    joint_range: dict[int, tuple[float, float]] = field(default_factory=_default_joint_range)

    counts_per_rev: int = 4096

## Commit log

2026-08-29 updated magnet dimension
2026-08-31 updated bearing dimension
2026-08-31 updated bearing_housing print settings
2026-09-02 uploaded assembly files
    [assembly.step]
2026-09-02 updated part design
    [link_elbow_to_wrist.stl, link_shoulder_to_elbow.stl, rubberband_housing.stl]
2026-09-04 updated with assembly guide
2026-09-06 updated screw hole placement
    [base_connector.stl]
2026-09-09 print file with all parts for bambulab a1
    [leader_arm_all_parts_bambulab_a1.3mf]
